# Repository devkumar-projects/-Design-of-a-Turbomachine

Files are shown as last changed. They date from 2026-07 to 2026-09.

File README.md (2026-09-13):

# Compact Axial Hydraulic Turbine — Integrated Turbomachinery Design

<p align="center">
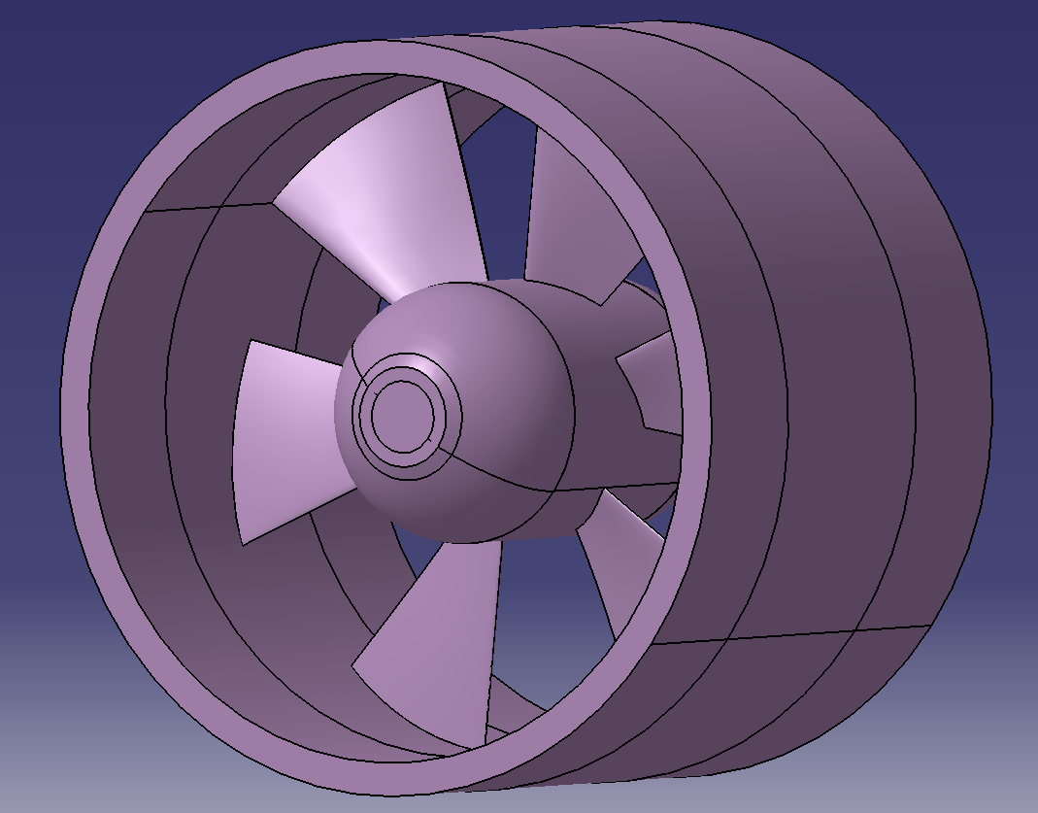
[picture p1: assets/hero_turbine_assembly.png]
Complete ducted axial-turbine CAD assembly
  
</p>

<p align="center">
  <em>Hydraulic sizing &middot; CAD &amp; structural verification &middot; CFD &middot; electromechanical conversion &middot; additive-manufacturing prototyping &middot; industrialisation</em>
</p>

<p align="center">
  
  
  
  
  
  
  
  
</p>

<p align="center">
  
</p>

## Overview

This repository documents the end-to-end engineering design of a **compact axial (Kaplan-type) hydraulic turbine**, carried out as a multidisciplinary study (*Bureau d'Etudes*) at **Arts et Metiers ParisTech (ENSAM)**. The project follows a single design thread from first principles to an industrial deployment scenario:

1. **Hydraulic preliminary sizing** in MATLAB, using similarity parameters and a digitised Cordier diagram.
2. **Blade-row and CAD modelling** in CATIA V5, with a preliminary finite-element check of the blade root.
3. **CFD analysis** in STAR-CCM+ (moving-reference-frame, steady segregated flow) to extract power, efficiency, and cavitation-risk trends.
4. **Electromechanical conversion**: a surface-mounted permanent-magnet synchronous generator pre-sized analytically and cross-checked with **FEMM/OctaveFEMM**, driving a PWM voltage-source converter modelled in **SIMBA**.
5. **Additive-manufacturing prototyping** (FFF, PLA) and **wind-tunnel testing** as a reduced-scale aerodynamic analogue of the hydraulic runner.
6. **Industrialisation study**: production planning, make-or-buy, location strategy, and a discounted business case for a 167-unit modular fleet.

The full write-up is included in [`docs/Compact_Axial_Hydraulic_Turbine_Report.pdf`](docs/Compact_Axial_Hydraulic_Turbine_Report.pdf).

> This was a **team project** (group GIE2-ED2, Semester 7): **Dev Kumar, Thien Ho, Seyf Daab, Wilhem Abboura**, supervised by **Christophe Sarraf, Florent Ravelet, Pascal Caestecker,** and **Jean-Frederic Charpentier**. This repository packages the MATLAB, FEMM, and SIMBA source files together with the consolidated report for portfolio purposes; the FEMM base template (`electromagnetic/femm`) was originally provided by J.-F. Charpentier and parameterised here for the project's operating point.

## Key results

| Stage | Metric | Value |
|---|---|---|
| Hydraulic design point | Speed / head / flow rate | 1500 rpm &middot; 3.8 m &middot; 0.132 m&sup3;/s |
| Runner envelope | Outer / hub radius | 103 mm / 39.1 mm |
| CFD baseline mesh | Cells / faces / vertices | 61,518 / 279,251 / 187,548 |
| CFD best operating point | Mechanical power @ flow rate | ≈ 1760 W @ 0.144 m&sup3;/s |
| Generator design torque | Electromagnetic torque | 152 N&middot;m |
| Prototype (wind-tunnel analogue) | Max. power coefficient / efficiency | C<sub>p</sub> ≈ 0.239 / η ≈ 0.56 |
| Industrial scenario | Fleet size / annual output | 167 units / ≈ 2 TWh/yr |
| Business case | ROI / payback | 21.5% / 2.4 years |

## Methodology

```mermaid
flowchart LR
    A[Cordier diagram\nsimilarity sizing] --> B[Velocity triangles\n+ blade mean line]
    B --> C[Modified NACA\nthickness law]
    C --> D[CATIA V5\nsurface + solid CAD]
    D --> E[Blade root FEA\nscreening]
    D --> F[STAR-CCM+ CFD\nmoving reference frame]
    F --> G[PMSM generator\nsizing + FEMM check]
    G --> H[PWM converter\n+ d-q current control\n SIMBA]
    D --> I[FFF prototype\n+ wind-tunnel test]
    F --> J[Industrialisation\n+ business case]
```

### Hydraulic sizing

The runner is sized from the engineering specific speed and the Cordier diagram:

```
Nsq = N * sqrt(qv) / H^0.75          (specific speed)
Omega = pi * Nsq / (30 * g^0.75)     (dimensionless specific angular velocity)
```

with the design point **N = 1500 rpm, N<sub>sq</sub> = 200, H = 3.8 m, q<sub>v</sub> = 0.132 m&sup3;/s**, giving an outer radius R<sub>e</sub> = 0.103 m and a hub radius R<sub>i</sub> = 0.039 m (hub-to-tip ratio 0.38).

Local velocity triangles then follow from the Euler turbine equation:

```
U(r)      = omega * r
Cu2_th(r) = -g*H / U(r)
beta_1(r) = atan( U(r) / Ca )
beta_2(r) = atan( (U(r) - Cu2(r)) / Ca )
```

### Electromechanical conversion

The generator's average electromagnetic torque follows from the fundamental air-gap flux density and the linear current loading:

```
<Cem> = sqrt(2) * B1 * A * V * cos(Psi)          (V = bore volume, A = linear current loading)
```

which is maximised for Ψ = 0 (current aligned with the EMF). The associated PWM converter is analysed for carrier-frequency sensitivity and closed-loop *d-q* current control.

## Repository structure

```
.
├── docs/
│   └── Compact_Axial_Hydraulic_Turbine_Report.pdf   # full write-up
├── matlab/
│   ├── hydraulic_sizing/     # Cordier sizing, velocity triangles, blade geometry, CATIA export
│   └── data_reduction/       # test-bench characteristic curves, affinity-law scaling
├── electromagnetic/
│   └── femm/                 # OctaveFEMM parametric PMSM field/flux/inductance script
├── simulink_simba/           # PWM converter + d-q current-control model (SIMBA)
├── cad/                      # STEP fluid-domain geometry used for the CFD study
├── data/                     # test-bench characteristic-curve dataset (multi-speed)
└── assets/                   # figures used in this README
```

## Tools and languages

| Domain | Tool |
|---|---|
| Hydraulic sizing, data reduction | MATLAB |
| Blade-section aerodynamics | XFoil |
| 3-D CAD, surfacing, structural screening | CATIA V5 (Generative Shape Design, Part Design, FEA) |
| CFD | Simcenter STAR-CCM+ |
| Electromagnetic field solving | FEMM / OctaveFEMM |
| Power electronics & control | SIMBA |
| Additive manufacturing | PrusaSlicer, FFF (PLA) |
| Experimental validation | Recirculating wind tunnel, 6-component balance |

## Selected figures

<table>
<tr>
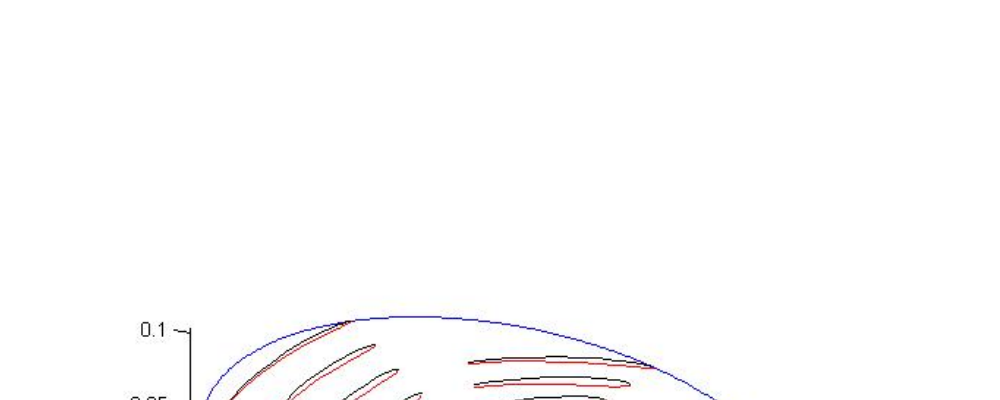
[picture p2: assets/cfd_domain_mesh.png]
<td><br><sub>Final blade-row geometry exported from the hydraulic sizing script</sub></td>
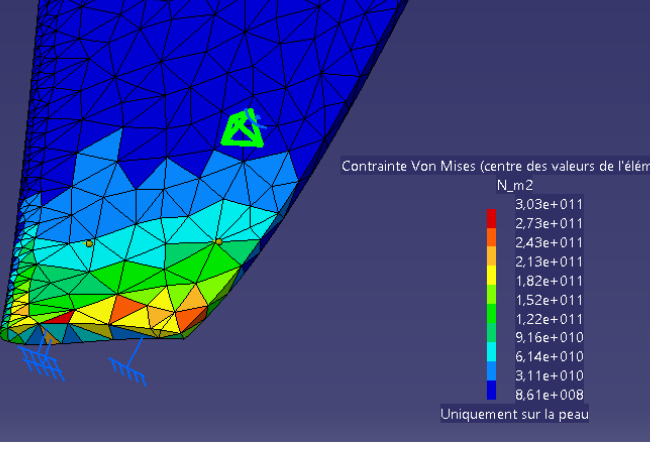
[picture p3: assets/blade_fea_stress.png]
<td><br><sub>Blade-root equivalent-stress distribution (finite-element screening)</sub></td>
</tr>
<tr>
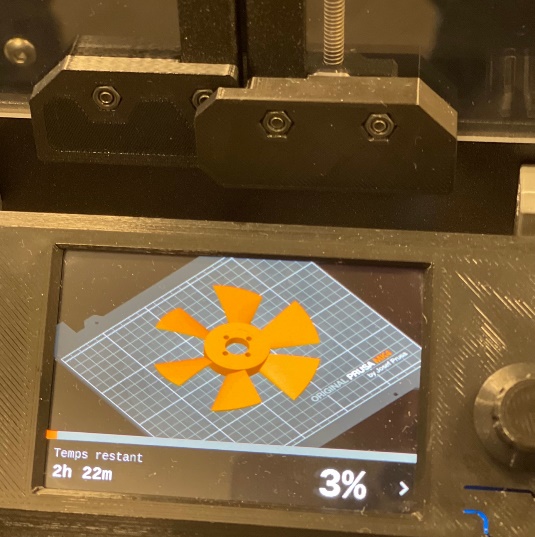
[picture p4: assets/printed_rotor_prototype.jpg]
<td><br><sub>FFF-printed PLA runner prototype</sub></td>
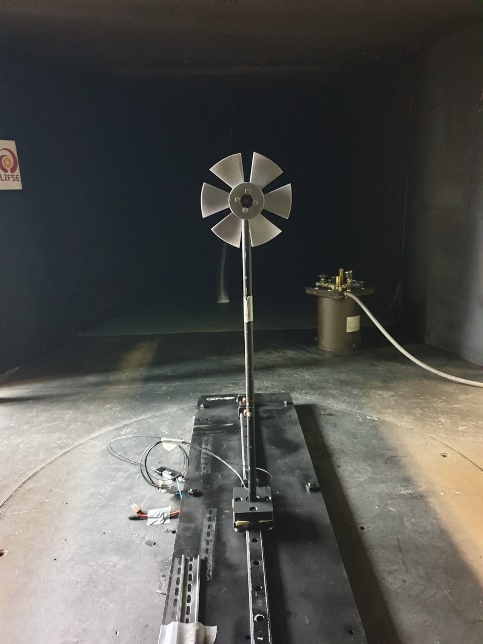
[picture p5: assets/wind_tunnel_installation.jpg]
<td><br><sub>Prototype installed in the recirculating wind-tunnel test section</sub></td>
</tr>
</table>

## Running the MATLAB scripts

```
matlab/hydraulic_sizing/main_turbine_sizing.m      % full sizing pipeline + CATIA point-cloud export
matlab/hydraulic_sizing/fit_naca_thickness.m       % modified NACA thickness-law identification (requires an XFoil point-save file)
matlab/hydraulic_sizing/cordier_digitisation.m     % Cordier-diagram specific-radius lookup
matlab/data_reduction/characteristic_curve_reduction.m   % reduces data/RIM_test_bench_data.xlsx into head/efficiency curves and BEPs
matlab/data_reduction/affinity_law_scaling.m       % turbine affinity-law speed scaling example
```

The FEMM script (`electromagnetic/femm/pmsm_femm_field_analysis.m`) requires a local [FEMM](http://www.femm.info/) installation and the OctaveFEMM/MATLAB toolbox. Set the `FEMM_MFILES` environment variable to FEMM's `mfiles` directory before running; the script no longer assumes a machine-specific Windows path or modifies MATLAB's global path.

The SIMBA model (`simulink_simba/pwm_converter_speed_control.jsimba`) can be opened directly in [SIMBA](https://simba.education/).

## License

This project is released under the [MIT License](LICENSE).

## Contact

Dev Kumar &middot; [dev-kumar.com](https://dev-kumar.com) &middot; contact@dev-kumar.com

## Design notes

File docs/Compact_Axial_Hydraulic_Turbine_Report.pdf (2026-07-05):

MULTIDISCIPLINARY ENGINEERING REPORT TURBOMACHINERY / ENERGY SYSTEMS

TURBOMACHINERY AND ENERGY CONVERSION

# Integrated Design of a Compact Axial Hydraulic Turbine

Hydraulic sizing, CAD and structural verification, CFD,
electromechanical conversion, prototyping, and industrialisation

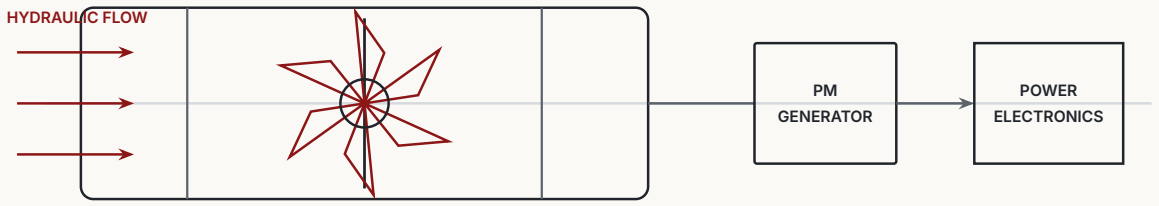
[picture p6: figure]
HYDRAULIC FLOW; PM GENERATOR; POWER ELECTRONICS

AUTHORS | Dev KUMAR · Thien HO · Seyf DAAB · Wilhem ABBOURA
SUPERVISORS | Christophe SARRAF · Florent RAVELET · Pascal CAESTECKER · Jean-Frédéric CHARPENTIER
INSTITUTION | École Nationale Supérieure d’Arts et Métiers
ACADEMIC TERM | Semester 7 — 2024 · Group GIE2–ED2
151 Boulevard de l’Hôpital, 75013 Paris, France

# Abstract

This report presents an integrated engineering study of a compact axial hydraulic turbine, from similarity-based hydraulic sizing to prototype testing and industrial deployment. The runner is pre-sized in MATLAB from a target speed of 1500 rpm, a specific-speed class Nsq = 200, a design head of 3.8 m, and an outer radius of 0.103 m. Velocity triangles and a modified NACA thickness law define the blade sections, which are exported to CATIA V5 for surface reconstruction, full rotor assembly, and preliminary finite-element verification. The resulting fluid domain is analysed in STAR-CCM+ using a moving reference frame and a baseline mesh of 61,518 cells. The reported optimum produces approximately 1760 W at 0.144 m³
s

−1
, below the initial 5 kW target and therefore motivating geometry refinement or a multi-unit architecture.
A surface-mounted permanent-magnet synchronous generator is then pre-sized from magnetic-circuit, induced-voltage, torque, and thermal relations. The associated voltage-source converter is examined through intersective PWM, carrier-frequency sensitivity, and closed-loop d–q current control. A PLA runner is manufactured by fused-filament fabrication and evaluated in a wind tunnel as a reduced-scale analogue. The experiment identifies a maximum power coefficient of approximately 0.239 and a peak efficiency of approximately 0.56. Finally, a modular industrial scenario based on 167 units is developed, including production planning, make-or-buy decisions, location strategy, and profitability. Under the source assumptions, the stated business case yields a 21.5% return on investment and a 2.4-year payback period. The study demonstrates the value of maintaining continuity between fluid mechanics, mechanical design, electrical conversion, experimental validation, and industrial decision-making.

KEYWORDS axial hydraulic turbine; Kaplan runner; Cordier diagram; STAR-CCM+; permanent-magnet synchronous generator; PWM converter; additive manufacturing; industrialisation.

i

# Project at a Glance

Ducted axial-turbine assembly developed in CATIA V5 and used to prepare the computational fluid domain.

HYDRAULIC DESIGN

N = 1500 rpm, H = 3.8 m, qv = 0.132 m³ s

−1
, Re = 0.103 m, and Ri =
0.03914 m.

DIGITAL ENGINEERING

MATLAB/XFoil blade synthesis, CATIA V5 surface and solid modelling, structural screening, and STAR-CCM+ moving-reference-frame CFD.

CFD BASELINE

61,518 cells, 279,251 faces, and 187,548 vertices; reported optimum P ≈ 1760 W at qv ≈ 0.144 m³
s

−1

EXPERIMENTAL RESULT

Additively manufactured PLA prototype; maximum measured power coefficient Cp ≈ 0.239 and peak efficiency η ≈ 0.56.

INDUSTRIAL SCENARIO

167 modular units, approximately 2 TWh/year target output, stated ROI 21.5%, and stated payback 2.4 years.

The equations, figures, numerical outputs, and engineering assumptions are retained from the original project report. The English prose, hierarchy, captions, scientific discussion, and publication design have been comprehensively edited for clarity and professional presentation.

ii

# Nomenclature

N , ω | Rotational speed and angular velocity.
Nsq, Ω | Engineering specific speed and dimensionless specific angular velocity.
H , qv | Net head and volume flow rate.
Re

, Ri

, r | Runner outer radius, hub radius, and local radius.
Ca
, U , Cu | Axial velocity, blade peripheral speed, and whirl-velocity component.
β1

, β2

, α2 | Blade inlet angle, blade outlet angle, and absolute discharge angle.
η, Cp | Efficiency and power coefficient.
P, M, C | Power and mechanical/electromagnetic torque.
B, H , μ | Magnetic flux density, magnetic field strength, and permeability.
p | Number of pole pairs.
ea

, eb

, ec | Phase electromotive forces.
id
, iq | Direct- and quadrature-axis current components.
Vdc, fc | DC-link voltage and PWM carrier frequency.
L, R, τ | Electrical inductance, resistance, and current-loop time constant.
Cp = 2P/(ρSV ³
) Aerodynamic power coefficient used in the wind-tunnel analogy.

iii

# Contents

1 Introduction | 1
2 Hydraulic Preliminary Design | 2
3 CAD Modelling and Structural Verification | 8
4 Computational Fluid-Dynamics Analysis | 11
5 Electromechanical Conversion System | 14
6 Additive Manufacturing and Experimental Validation | 26
7 Industrialisation and Market Deployment | 30
8 Conclusion | 39
A MATLAB and XFoil Routines | 40

iv

# List of Figures

2.1 Digitised Kaplan-turbine region of the Cordier diagram | | 2
2.2 MATLAB interpolation of the Cordier data used to identify the specific radius | | 3
2.3 Graphical solution used to determine the design head | | 4
2.4 Radial distribution of blade speed and whirl-velocity components | | 4
2.5 MATLAB output for inlet, outlet, and discharge angles at selected radii | | 5
2.6 Construction of the blade-section mean line from the local inlet and outlet angles | | 5
2.7 Relative blade-thickness law from hub to tip | | 6
2.8 Comparison between the initial NACA profile and the modified, thicker section | | 6
2.9 MATLAB reconstruction of the blade section from raw points and the fitted thickness law. . . . | 6
2.10 Optimised polynomial coefficients returned by MATLAB | | 7
2.11 Final blade-row geometry obtained after scaling and circumferential replication | | 7
3.1 Transfer of the analytical blade definition into the CAD environment | | 8
3.2 Equivalent-stress distribution in the blade under the prescribed surface loading | | 9
3.3 Progressive construction of the complete runner | | 9
3.4 Complete ducted-turbine CAD assembly | | 9
3.5 Principal CAD dimensions of the ducted runner | 10
3.6 Fluid-domain volumes extracted from the complete CAD assembly | 10
4.1 Computational-domain definition and baseline discretisation | 11
4.2 Detail of the computational mesh in the runner region | 12
4.3 Convergence assessment of the baseline CFD computation | 12
4.4 Representative CFD field used for performance interpretation | 12
4.5 Performance curves extracted from the STAR-CCM+ operating-point sweep | 13

5.1 Cross-section of the permanent-magnet synchronous machine used for the preliminary model. . 14
5.2 Winding layout, showing the outgoing and return conductors for each phase | 14
5.3 Stator-fixed angular reference used for the harmonic field representation | 15
5.4 Flux-cutting principle for a conductor moving through a magnetic field | 15
5.5 Idealised radial air-gap flux-density waveform created by the surface magnets | 17
5.6 Sizing interface used to define the generator geometry and magnetic loading | 19
5.7 Numerical outputs of the preliminary generator-sizing model | 19
5.8 Global speed-control architecture implemented in the simulation environment | 20
5.9 Representative ideal-source and PWM voltage waveforms | 21
5.10 Time-domain and spectral comparison of the ideal and PWM voltages | 21
5.11 PWM phase voltage compared with the ideal sinusoidal phase voltage | 21
5.12 Discrete Fourier transform of the converter output | 22
5.13 Ideal and PWM-fed phase-current comparison | 22
5.14 Modified carrier-frequency and inductance configuration | 23
5.15 Comparison used to assess the influence of carrier frequency | 23
5.16 Voltage and current response after increasing the DC-link voltage limit to 350 V | 24
5.17 Torque-model implementation and sensitivity to the current-to-EMF angle | 24
5.18 Principal blocks of the closed-loop current-control model | 24
5.19 Rotational-speed reference, measured speed, and electromagnetic torque | 25
5.20 Current components and their references during the speed-control sequence | 25
6.1 Preparation and execution of the fused-filament fabrication process | 26
6.2 Sliced geometry and support strategy | 26
6.3 Post-processing stages of the additively manufactured turbine | 27

v

vi List of Figures

6.4 Installed turbine prototype in the wind-tunnel test section | 27
6.5 Schematic representation of the recirculating wind-tunnel facility | 29
6.6 Wind-tunnel installation of the turbine prototype | 29
7.1 Comparison of potential French regions for turbine industrialisation and deployment | 31
7.2 Comparison of turbine technologies for the selected regional conditions | 33
7.3 Large Kaplan units compared with smaller modular turbines | 33
7.4 Compact bulb-turbine concept adopted for the industrial scenario | 34
7.5 Sales and operations plan, including annual production and safety stock | 34

CHAPTER 1

# Introduction

Hydraulic turbines have converted the energy of flowing water into useful mechanical power for centuries. From early water wheels to modern axial-flow machines, their development has been driven by the same engineering objective: extracting energy efficiently while maintaining structural integrity and operational reliability. In the present context of decarbonisation, distributed generation, and grid resilience, small and medium hydroelectric systems remain particularly attractive because they combine a mature conversion principle with low operational emissions and long service life.
This project addresses the end-to-end design of a compact axial hydraulic turbine and its associated electromechanical conversion chain. The work deliberately spans several engineering disciplines. Hydraulic preliminary sizing is first performed in MATLAB using similarity parameters and the Cordier diagram. Blade sections are then generated with XFoil-derived profiles and transferred to CATIA V5 for three-dimensional modelling and structural verification. The complete flow domain is analysed in STAR-CCM+ to assess the velocity and pressure fields, mechanical power, efficiency, and cavitation risk. A permanent-magnet synchronous generator and its power-electronic conversion chain are subsequently pre-sized and studied. Finally, a polymer prototype is manufactured by fused-filament fabrication, tested in a wind tunnel as an aerodynamic analogue, and embedded in an industrial and commercial deployment study.
The study is therefore organised around six coupled work streams:
1. Hydraulic preliminary design - definition of the operating point, characteristic radii, velocity triangles, blade angles, and section thickness law.
2. Blade and turbine CAD - point-cloud export, surface generation, finite-element verification, and construction of the complete rotor and fluid domains.
3. Computational fluid dynamics - mesh generation, moving-reference-frame simulation, convergence assessment, performance extraction, and cavitation screening.
4. Electromechanical conversion - preliminary design of a surface-mounted permanent-magnet synchronous generator and analysis of the PWM-fed variable-speed drive.
5. Prototype manufacture and experimental validation - additive manufacture, wind-tunnel measurements, and identification of the power coefficient and efficiency.
6. Industrialisation - market positioning, production planning, resource requirements, make-or-buy decisions, location strategy, and financial viability.

The resulting document is intended as a coherent engineering publication rather than a sequence of isolated laboratory exercises. Assumptions are stated explicitly, equations are retained in their original mathematical form, and each numerical stage is connected to the physical design decisions that follow.

1

CHAPTER 2

# Hydraulic Preliminary Design

### 2.1 Design brief and operating point

The first stage establishes a hydraulic pre-design for an axial-flow turbine. The initial specification is:
- rotational speed: N = 1500 rpm;
- specific-speed class: Nsq = 200;
- maximum available net head: H = 4 m;
- penstock and runner outer radius: Re = 0.103 m.
The process comprises three linked tasks: MATLAB-based sizing of the runner, construction of the blade geometry, and subsequent preparation of the complete fluid domain for CFD analysis. The MATLAB implementation is reproduced in the appendices.

### 2.2 Similarity parameters and Cordier selection

The angular velocity is

ω =

2 × π × N
60

= 157.07 rad.s⁻¹

The dimensionless specific angular velocity is written as

Ω = ω√qv
(gH )

3
4

=

π.N
30

×√qv
(gH )

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
Nsq =

N√qv
H

3/4,
which gives

Ω=

π.Nsq
30.g

3
4

= 3.778.

The Kaplan region of the Cordier diagram was digitised with Engauge and imported into MATLAB. This provided a reproducible estimate of the specific radius rather than a purely graphical reading.

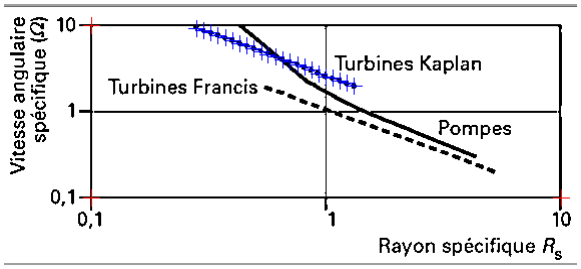
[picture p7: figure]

Figure 2.1: Digitised Kaplan-turbine region of the Cordier diagram.
The linear fit used in the selected interval is
Ω(Rs

) = 9.224−1.987
0.2804−1.31

Rs + 8.705 = −7.03Rs + 8.70. Solving Ω(Rs

) = 3.778 gives

2

Head, flow rate, and runner radii 3

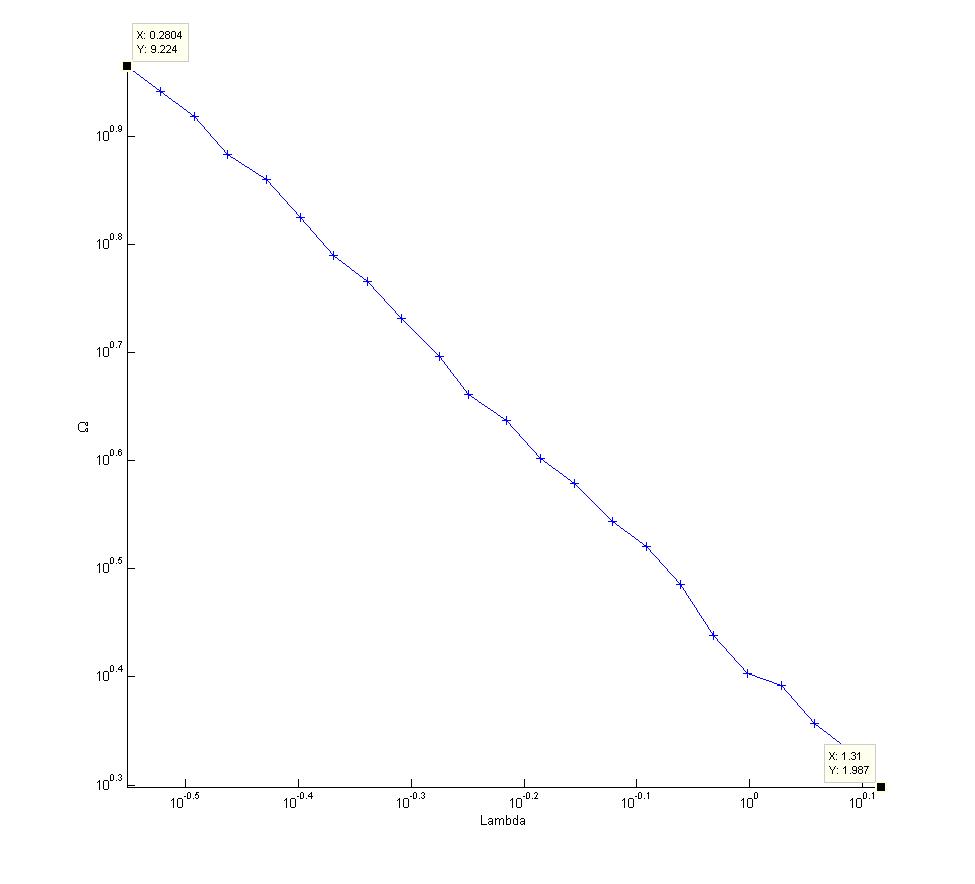
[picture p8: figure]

Figure 2.2: MATLAB interpolation of the Cordier data used to identify the specific radius.

Rs = 0.701.

### 2.3 Head, flow rate, and runner radii

The head and volume-flow relations are

Ω =

ω√qv
(gH )

3
4

, Λ =

R(gH )

1
4
√qv

The selected operating values are

H = 3.8 m
and
Nsq = | N√qv
| H
| 3
| 4

,

qv = 0.132 m³

| .s⁻¹
The hub radius is defined from the hub-to-tip ratio T = 0.38: Ri = ReT , with Re = 0.1030 m, hence

Ri = 0.03914 m.
The axial velocity component is

### 4 Hydraulic Preliminary Design

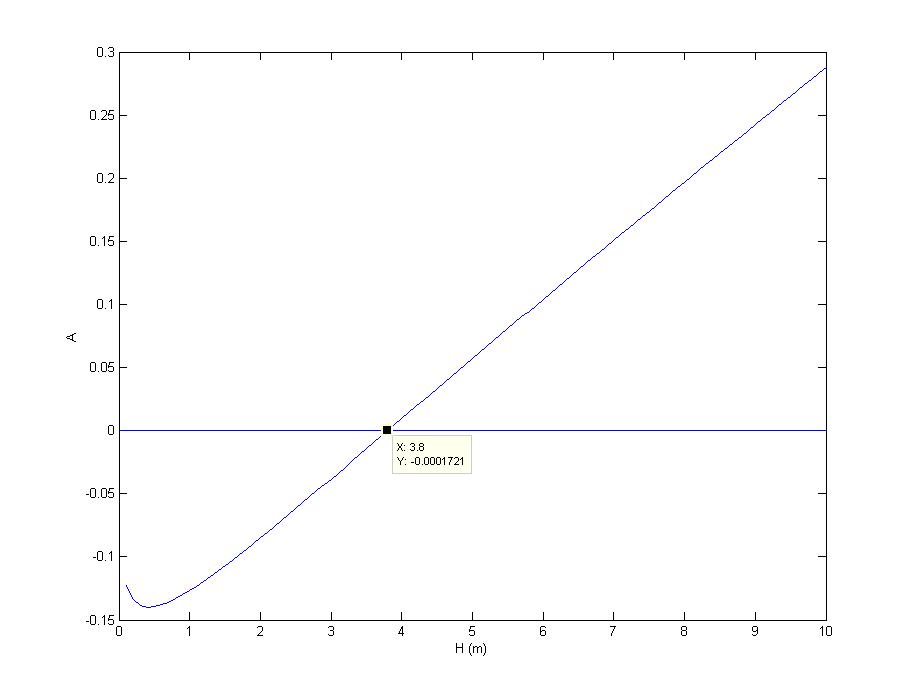
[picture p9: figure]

Figure 2.3: Graphical solution used to determine the design head.

Ca =

qv
S

=

qv
π (R²

e −R²
i

)

,

Ca = 4.629 m.s⁻¹
The circumferential speed and theoretical and corrected whirl components are evaluated over Ri < r < Re

Figure 2.4: Radial distribution of blade speed and whirl-velocity components.

### 2.4 Velocity triangles and blade mean line

The inlet, outlet, and discharge angles (β1

, β2

, α2

) are calculated directly in MATLAB from the local velocity triangles.
The calculated values of β1 and β2

remain between 30∘

and 80∘
, which is consistent with the adopted axialrunner design range. The blade-section mean line is generated by the function LigneK.m. Assuming a linear evolution of the local tangent between the inlet and outlet angles,

dyy = (tan β2 − tan β1

) xx2 + tan β1

Thickness law and modified NACA section 5

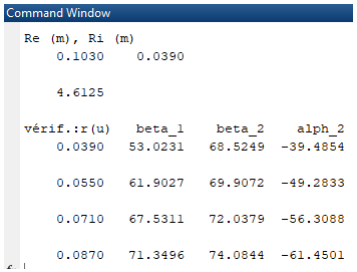
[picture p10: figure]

Figure 2.5: MATLAB output for inlet, outlet, and discharge angles at selected radii.

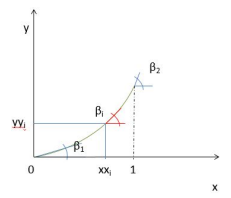
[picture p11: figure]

Figure 2.6: Construction of the blade-section mean line from the local inlet and outlet angles.

The full MATLAB routine is provided in Appendix A. It returns both the mean-line ordinate and the local blade angle required for the subsequent thickness distribution.

### 2.5 Thickness law and modified NACA section

Mechanical strength requires a blade that is thick near the hub and progressively thinner toward the tip. The adopted relative-thickness law is therefore defined as a function of radius.
Standard NACA profiles were found to be too thin for the intended prototype and structural constraints. A thicker profile was generated and fitted to a modified polynomial thickness law using XFoil data and MATLAB optimisation.
In the reconstruction, the red curve represents the upper surface, the green curve the normalised thickness law, and the blue curve the original point set. The function fminsearch(f,x0) is used to minimise the quadratic discrepancy between the measured and analytical profiles.
The resulting section is scaled according to the local solidity, defined here as the chordwise spacing relationship between adjacent blades. The final runner geometry is shown below.

### 6 Hydraulic Preliminary Design

Figure 2.7: Relative blade-thickness law from hub to tip.

Figure 2.8: Comparison between the initial NACA profile and the modified, thicker section.

Figure 2.9: MATLAB reconstruction of the blade section from raw points and the fitted thickness law.

Thickness law and modified NACA section 7

Figure 2.10: Optimised polynomial coefficients returned by MATLAB.

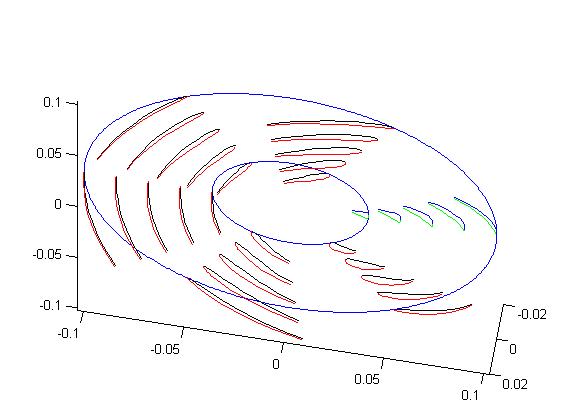
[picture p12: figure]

Figure 2.11: Final blade-row geometry obtained after scaling and circumferential replication.

CHAPTER 3

# CAD Modelling and Structural Verification

### 3.1 Point export and surface generation

Once the analytical blade geometry had been defined, MATLAB was used to decompose each section into a set of three-dimensional points. These point clouds were exported to CATIA V5, where the blade surfaces were reconstructed with the Generative Shape Design workbench. This workflow preserves the radial evolution of chord, thickness, and stagger angle while providing a CAD model suitable for both structural analysis and additive manufacture.

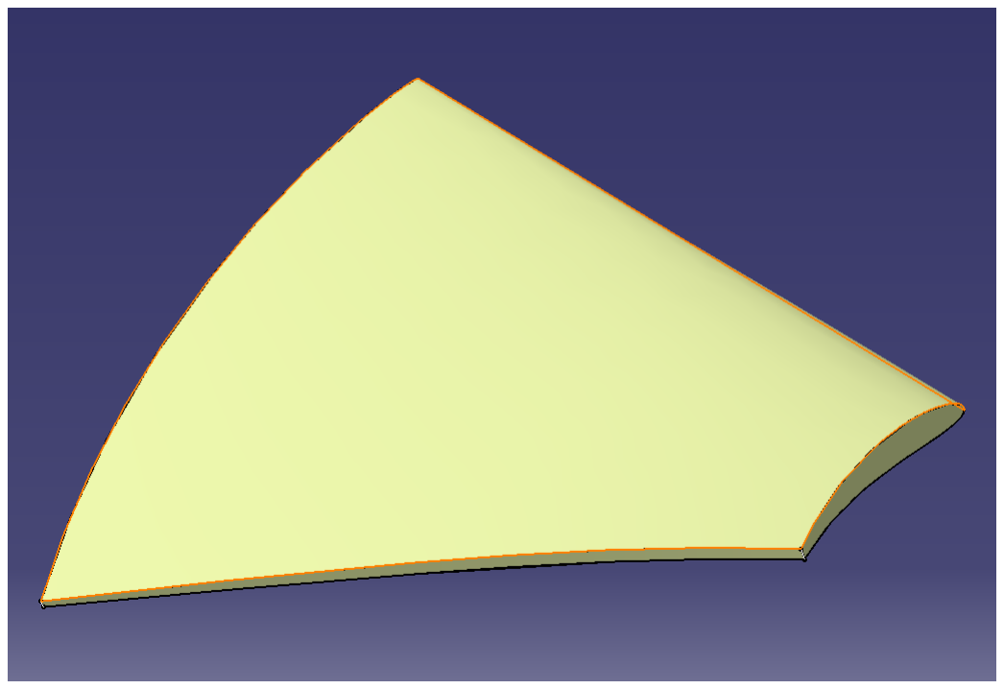
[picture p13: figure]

(a) MATLAB blade-section curves before CAD export. | (b) CATIA V5 surface reconstructed from the imported sections.

Figure 3.1: Transfer of the analytical blade definition into the CAD environment.

### 3.2 Finite-element verification of the blade

A preliminary finite-element analysis was performed to verify that the modelled blade could withstand the distributed fluid loading. Surface tractions were applied to the pressure and suction sides, while the blade root was fixed. The highest equivalent stresses occur, as expected, near the root constraint.
The maximum calculated stress remains below the elastic limit of the selected material within the assumptions of the model. The analysis therefore supports continuation to the full rotor assembly, while also identifying the root transition as the principal area for future mesh and geometry refinement.

### 3.3 Rotor, hub, and duct assembly

The individual blade was replicated circumferentially using the CATIA Part Design circular-pattern tool.
The hub was then modelled so that its outer diameter remained compatible with the blade-root envelope. A surrounding duct was divided into three axial regions. This partitioning was introduced specifically to define the inlet, rotating, and outlet fluid-domain interfaces required by STAR-CCM+.
A two-dimensional drawing was generated to retain the principal dimensions and assembly envelope. Finally, the solid geometry was used to construct the fluid volumes for CFD.

8

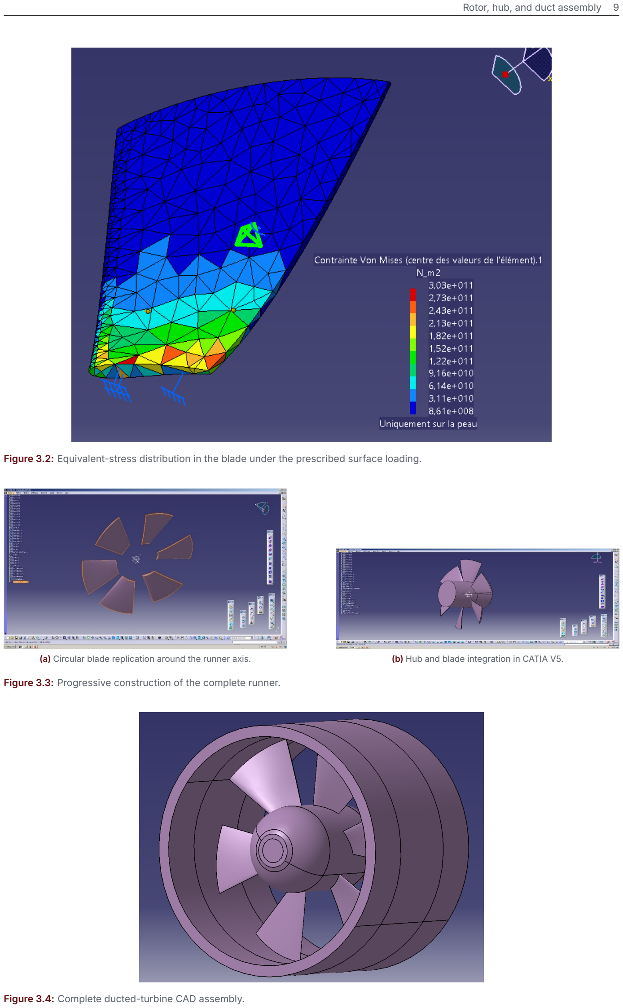
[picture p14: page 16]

Rotor, hub, and duct assembly 9

Figure 3.2: Equivalent-stress distribution in the blade under the prescribed surface loading.

(a) Circular blade replication around the runner axis. | (b) Hub and blade integration in CATIA V5.

Figure 3.3: Progressive construction of the complete runner.

Figure 3.4: Complete ducted-turbine CAD assembly.

### 10 CAD Modelling and Structural Verification

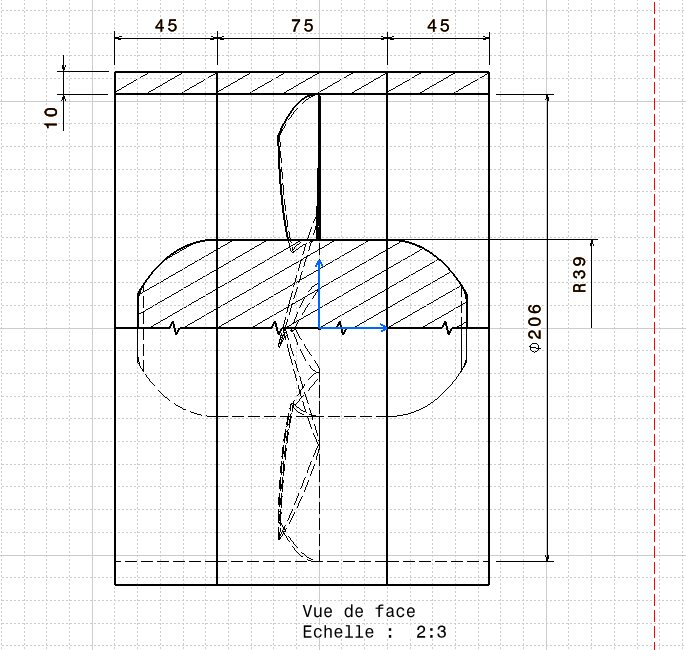
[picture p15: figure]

Figure 3.5: Principal CAD dimensions of the ducted runner.

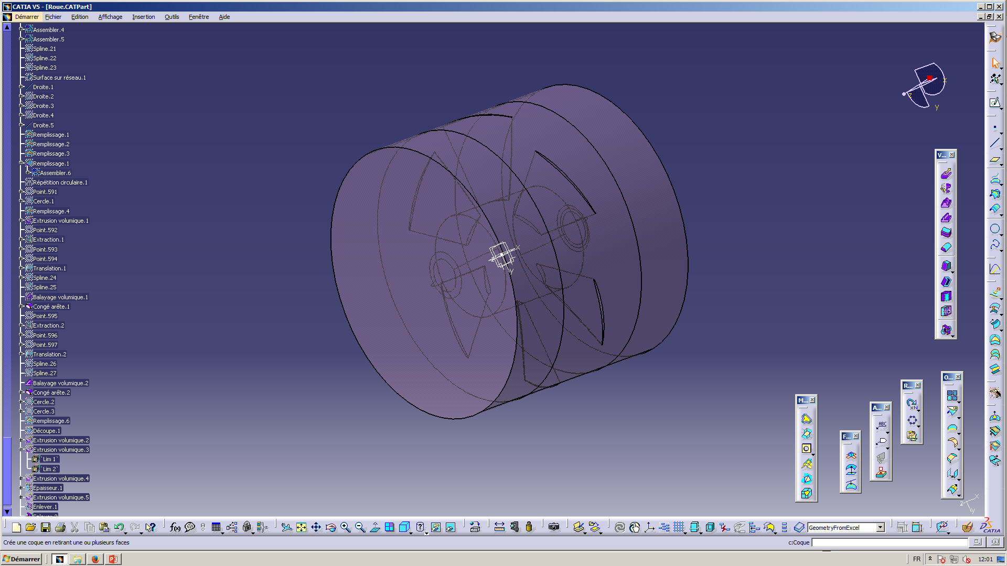
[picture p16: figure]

Figure 3.6: Fluid-domain volumes extracted from the complete CAD assembly.

CHAPTER 4

# Computational Fluid-Dynamics Analysis

### 4.1 Numerical model and mesh

The STAR-CCM+ study was configured to verify the following design targets:

- N = 1500 rpm;
- Nsq = 200;
- H = 4 m;
- R = 0.103 m;
- target hydraulic efficiency η = 0.92;
- target power P = 5 kW.

The inlet and outlet surfaces were defined at the ends of the extended flow domain. Additional upstream and downstream lengths were retained to prevent the solution from being dominated by the immediate blade-wake structures.
A combined surface and volume mesh was generated.
(a) Inlet, rotating-domain interfaces, and outlet. | (b) Surface and volume mesh of the fluid domain.

Figure 4.1: Computational-domain definition and baseline discretisation.

The baseline mesh contains 61,518 cells, 279,251 faces, and 187,548 vertices.

### 4.2 Physical models and reference frame

A segregated-flow formulation was selected to reduce computational cost and memory demand while maintaining acceptable convergence for the available computing resources. Rotor motion was represented with a moving reference frame. This formulation permits the rotating region to be treated in a steady framework while preserving the apparent inertial effects associated with rotation. The reference pressure was set to 101,300 Pa.

11

### 12 Computational Fluid-Dynamics Analysis

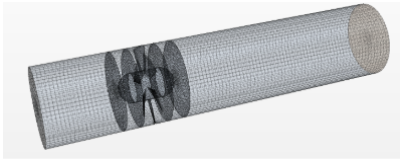
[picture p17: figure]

Figure 4.2: Detail of the computational mesh in the runner region.

### 4.3 Convergence assessment

The stopping criterion was set to 1000 iterations, with the residual level expected to fall below 10⁻³. The residual history confirms that this iteration count provides a sufficiently settled baseline solution for the present comparative design study.

(a) Residual convergence history. | (b) Independent monitor confirming solution stabilisation.

Figure 4.3: Convergence assessment of the baseline CFD computation.

If convergence were not achieved, the appropriate response would be to revisit the boundary conditions, pressure level, mesh quality, turbulence treatment, or iteration budget rather than interpreting an unconverged field.

### 4.4 Performance extraction and interpretation

The flow-field results were post-processed to obtain the hydraulic torque, mechanical power, and efficiency trends.

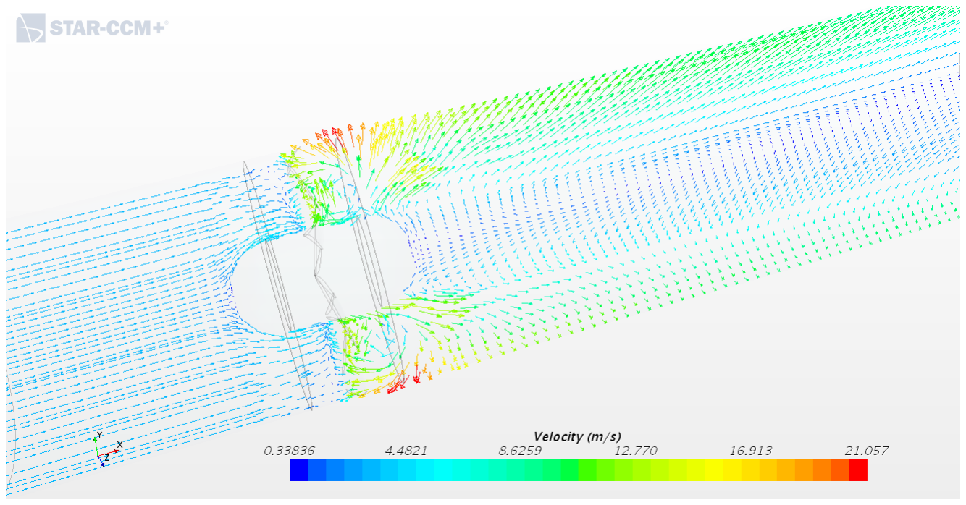
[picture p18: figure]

Figure 4.4: Representative CFD field used for performance interpretation.

The available mechanical power is calculated from

Pm = CΩ = MΩ.

Performance extraction and interpretation 13

Figure 4.5: Performance curves extracted from the STARCCM operating-point sweep.
The best simulated operating point occurs at approximately qv = 0.144 m³ .s

−1
, with a mechanical power of about 1760 W and a corresponding head of H = 3.60 m. This result does not reach the initial 5 kW target for a single unit, but it indicates that prioritising efficiency and using two units may be preferable to forcing one runner toward a less favourable operating point.
Cavitation becomes possible when the local static pressure falls below the saturation pressure. The highestrisk regions are therefore expected near leakage paths and blade edges, where local velocity peaks produce the strongest pressure depression.
The numerical study identifies four principal improvement directions:
- refine the blade-row geometry to optimise the balance between solidity, loading, and friction;
- increase mesh resolution in the blade boundary layers, tip region, and wake;
- revisit the single-unit 5 kW objective and evaluate a multi-unit architecture;
- adopt a less optimistic efficiency assumption during early-stage sizing.

Within the limits of the mesh and steady moving-reference-frame model, the CFD study completes the hydraulic pre-design and provides the loading and operating-point information required for the electrical and prototype stages.

CHAPTER 5

# Electromechanical Conversion System

### 5.1 Preliminary design of a permanent-magnet synchronous generator

The hydraulic runner is coupled to a surface-mounted permanent-magnet synchronous machine operated as a generator. The purpose of this section is to establish a first set of electromagnetic dimensions at the selected operating point and to derive the relationships governing induced voltage, electromagnetic torque, magnet loading, and active length.

Figure 5.1: Cross-section of the permanent-magnet synchronous machine used for the preliminary model.
The magnets are mounted on the rotor surface, surrounding the previously designed turbine. The ferromagnetic laminations form high-permeability magnetic circuits, while the phase windings are placed in stator slots.

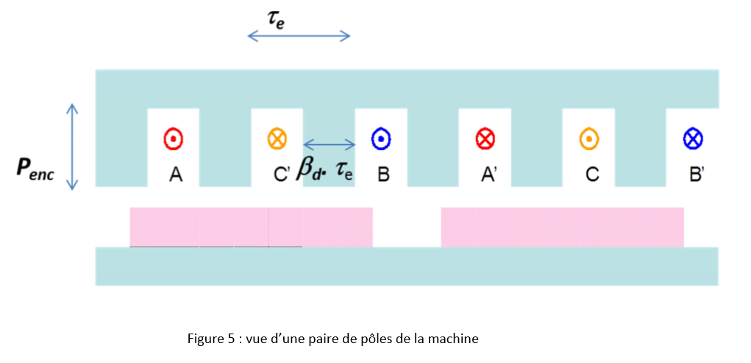
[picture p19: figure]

Figure 5.2: Winding layout, showing the outgoing and return conductors for each phase.

The end effects are neglected, allowing the machine to be analysed in two dimensions. The model therefore assumes an axially uniform machine in which the displayed section is representative of any section along the

14

Preliminary design of a permanent-magnet synchronous generator 15

active length. The permeability of the ferromagnetic yokes is treated as very high relative to the air gap and magnet regions.

### 5.1.1 Preliminary magnetic relations

For a linear medium,
B = μ ⃖⃗ H⃖⃖⃗.
For air,
⃖⃖⃖⃗ B0 = μ0
| ⃖⃖⃖⃗ H0 ,
and for the iron,
B = μ ⃖⃗ 0μrH⃖⃖⃗, with μr > 1000. For the permanent magnet,

⃖⃗B=μ0

⃖⃖⃗H+⃖⃖⃖⃗ Br

### 5.1.2 Electromotive forces and average torque

When the rotor turns relative to the stator, the magnet field induces phase electromotive forces. In a stator-fixed reference frame,

Figure 5.3: Stator-fixed angular reference used for the harmonic field representation.

B (θ, t) =

∞
∑
k=0

B2k+1cos[p (2k + 1) (θ − Ωt)],

where p is the number of rotor pole pairs and Ω is the mechanical angular velocity in radians per second. The flux-cutting relation is illustrated below.

Figure 5.4: Flux-cutting principle for a conductor moving through a magnetic field.

For a conductor moving at velocity ⃖⃗v,

e = l |

⃖⃗BΛ⃖⃗v| = lBv if ⃖⃗B⟂⃖⃗v.

With LxB = φ,
dφ
dt =

dx
dt LB = vLB.

### 16 Electromechanical Conversion System

For phase A, with D denoting the air-gap diameter,

econdA= B (0, t) ∗

ΩD
2

L,

econdA′ = B (

π
2

, t)

ΩD
2

L = −econdA.

Because one turn contains two active conductors, N conductors correspond to N /2 turns. Accounting for the pole count, the phase-A electromotive force becomes

ephaseA=ΣecondA−ΣecondA′= nB (0, t)

ΩD
2

L.

The two other phase voltages are shifted by 2π/3 and 4π/3:

ephaseB= nB (

2π
3p

, t)

ΩD
2

L,

ephaseC= nB (

4π
3p

, t)

ΩD
2

L.

Assuming balanced sinusoidal currents,

i
i

(t) = I√2 cos (ωt − Ψ − (i − 1) 2π 3

) , ω = pΩ.

The instantaneous electromagnetic power is

Pem(t) =

3
∑
i=1

ei

i

i = n

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
Bk+1 cos [(2k + 1) ((i − 1) 2π 3

− ωt)] cos (ωt − Ψ − (i − 1) 2π 3

) .

All higher-order terms have zero mean over an electrical period; only the fundamental contributes to the average power:

⟨pem⟩ = I√2nΩD
2

L

3
∑
i=1

B1 cos ((i − 1) 2π
3

− ωt) cos (ωt − Ψ − (i − 1) 2π 3

) ,

⟨pem⟩ =

3
2

I√2nΩD
2

Lcos(Ψ).

Using the linear current loading A = 3nI
πD

and bore volume V = πD²L
4

= πR²L,

⟨Cem⟩ =

⟨pem⟩
Ω

=

3
2√2

nB1

IDL cosΨ = 3
2√2

AπD
3

DB1L cosΨ,

⟨Cem⟩ =√2B1AV cos(Ψ).
The maximum torque is obtained for Ψ = 0:

⟨Cem⟩max =√2B1AV.

### 5.2 Magnet thickness and fundamental air-gap flux density

The air gap is assumed sufficiently small for the induction in the gap and the magnet to be predominantly radial. Curvature and load-current effects are neglected, and the ferromagnetic yokes are assumed to have infinite permeability. The magnet characteristic is
B = μ0H + Br
Ampere’s law is applied to a contour crossing the two magnets and the two air gaps:

Magnet thickness and fundamental air-gap flux density 17

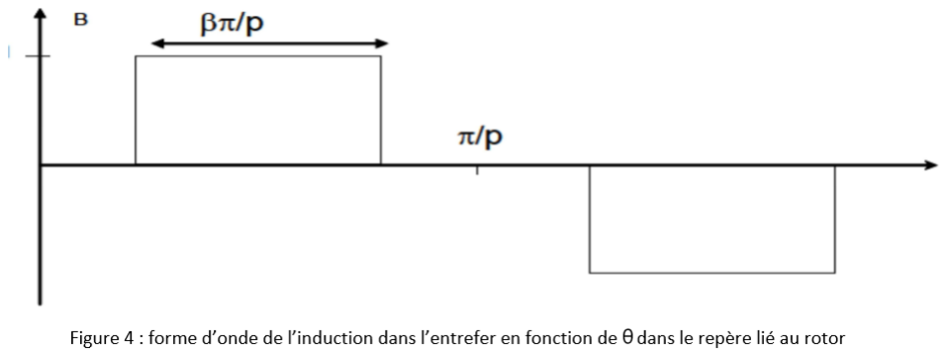
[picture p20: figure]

Figure 5.5: Idealised radial air-gap flux-density waveform created by the surface magnets.

⃖⃖⃖⃗ rot (H⃖⃖⃗) = J →⃖⃗

⎧
⎨
⎩
B = μ ⃖⃗ | 0H⃖⃖⃗ in air
B = μ ⃖⃗ | 0μrH⃖⃖⃗ in iron, μr > 1000
B = μ ⃖⃗ | 0H + ⃖⃖⃗ ⃖⃖⃗Br
in the magnet
Because no current is enclosed,

∮ H ⋅ ⃖⃖⃗ ⃖⃖⃗dl = 0.

The field intensity in the iron is negligible compared with that in the air gap:
Hf er =

Bf er
μ0μr

≪ Hair .
The magnetic-circuit equation therefore reduces to

2Haea + 2Hgg = 0, Ba = Bg = ̂B.

With
⎧
⎪
⎨
⎪
⎩

Bg = μ0Hg → Hg =

B̂
μ0
Ba = μ0Ha + Br
Ha =

B−B ̂ r
μ0

,

one obtains

̂B=

eaBr
g + ea

For g = 1 mm and ea varied from 0.1 to 10 mm, the relationship is initially nearly linear and asymptotically approaches Br

. Excessive magnet thickness therefore adds material with progressively smaller electromagnetic benefit.
The first harmonic of the rectangular air-gap field is

a1 =

2
T

∫

T /2

−T /2

f (T ) cos(ωt)dt,

which gives

B1 = a1 =

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
B(θ) cos(pθ)dθ = 4
π

B̂sin (

βπ
2

) ,

B1=

4
π

̂Bsin (

βπ
2

) .

### 18 Electromechanical Conversion System

### 5.3 Dimensional model at the nominal operating point

The machine is sized for a nominal power and speed (Pn

, Ωn

). The principal prescribed quantities are summarised below.

Symbol Definition
J | RMS current density in the conductors (A/mm²
)
AL

linear current loading
kr

slot fill factor
D | air-gap diameter
Be,max | maximum air-gap induction
Br | magnet remanent flux density
g | air-gap length
Bsat | saturation flux density
fmax | maximum electrical frequency

The slot fill factor is

kr =

∑ Scond

Sslots

,

where Scond is the conductor cross-sectional area.

### 5.3.1 Thermal and electromagnetic constraints

Copper losses and convection establish the principal thermal constraint:

PJ = 3nRcond I

2 = 3nρ L
Scond

I

2 = ρ3nI LJ = ρπDL AJ ,

ΔT ∼

PJ

ℎSext

, Sext ∼ πDL,

ΔT ∼

ρAJ
h

Representative design ranges are

J ∈ [3 × 10⁶

, 7 × 10⁶

] A/m²
,

A ∈ [12,000, 60,000] A/m.
At the nominal point,

PN = CemΩN , Cem =

PN

ΩN

=

PN
πN
30p

,

which gives

Cem = 152 Nm.
The active length is selected while respecting magnetic saturation. With

X = B̂
Br

,

Variable-speed drive and PWM converter 19

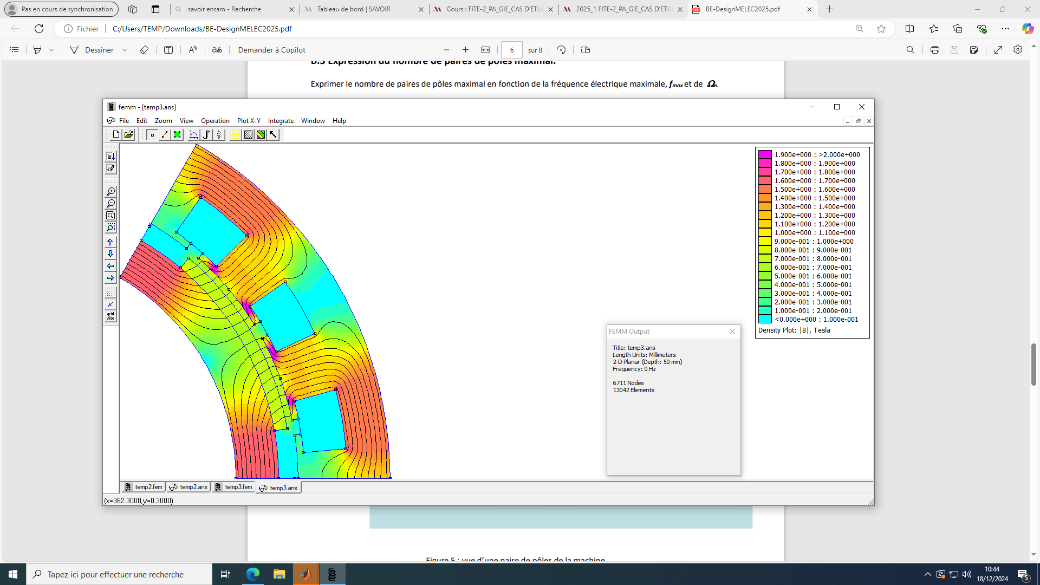
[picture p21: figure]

Figure 5.6: Sizing interface used to define the generator geometry and magnetic loading.

B = X B ̂ | r
, | B1 =

4
π

B̂sin (

βπ
2

) ,

Cem = √2AD²LBr

sin (

βπ
2

) ,

one obtains

L = | C
√2AXBrD²

sin (

βπ
2

)

The resulting parameter set is then introduced into the numerical model to calculate flux linkage as a function of rotor position and phase and to verify the electromagnetic design.

(a) Generator pre-sizing parameters and principal numerical results. | (b) Complementary machine-design output used for finite-element validation.

Figure 5.7: Numerical outputs of the preliminary generator-sizing model.

This stage provides a consistent first-order geometry for the permanent-magnet synchronous generator at the selected torque-speed point.

### 5.4 Variable-speed drive and PWM converter

The second electrical study concerns the conversion chain formed by the permanent-magnet synchronous machine and a voltage-source inverter controlled by pulse-width modulation (PWM). The objective is to understand the variable-speed control principle and evaluate the influence of switching and filtering parameters on the phase currents.

### 5.4.1 Global speed-control architecture

The rotating-system dynamics may be expressed in the generic form J

dΩ
dt = Cem − Cload ,
where J is the total rotating inertia, Ω the rotational speed, Cem the electromagnetic torque, and Cload the

### 20 Electromechanical Conversion System

torque imposed by the turbomachine.
The control structure compares the speed reference with the measured speed, uses a PI/PID controller to produce a torque reference, and applies vector control so that the phase currents remain synchronised with the machine electromotive forces.

Figure 5.8: Global speed-control architecture implemented in the simulation environment.

For phase i,

φi = φm√2 cos (θ − (i − 1) 2π 3

) ,

ei = −

dφi
dt =

dφi
dθ

dθ

dt = √2φmω sin (θ − (i − 1) 2π 3

) .

The electrical power relations are P = 3V I cos α,

Pe = 3EI cos ψ ,
and

Cem=

Pe
Ω

= 3 E
Ω

I cos ψ .

If the current-to-EMF angle is maintained constant, the torque is proportional to the sinusoidal current amplitude. Adjusting this amplitude therefore provides direct torque control while preserving synchronism with the machine EMFs.

### 5.4.2 Ideal source and intersective PWM comparison

The SIMBA model VSI-vs-Perfect-V compares two supply configurations:

1. an ideal three-phase sinusoidal voltage source;
2. a voltage-source inverter controlled by intersective PWM.

The PWM converter generates a pulse train whose duty ratio varies with the sinusoidal reference. The ideal source contains only the fundamental component, whereas the PWM voltage includes switching harmonics concentrated around the carrier frequency and its multiples.
A second converter analysis confirms the same behaviour.

Variable-speed drive and PWM converter 21

Figure 5.9: Representative ideal-source and PWM voltage waveforms.

Figure 5.10: Time-domain and spectral comparison of the ideal and PWM voltages.

Figure 5.11: PWM phase voltage compared with the ideal sinusoidal phase voltage.

### 22 Electromechanical Conversion System

The fundamental remains at 50 Hz, while additional components appear around 2 kHz and 4 kHz for the selected carrier frequency.

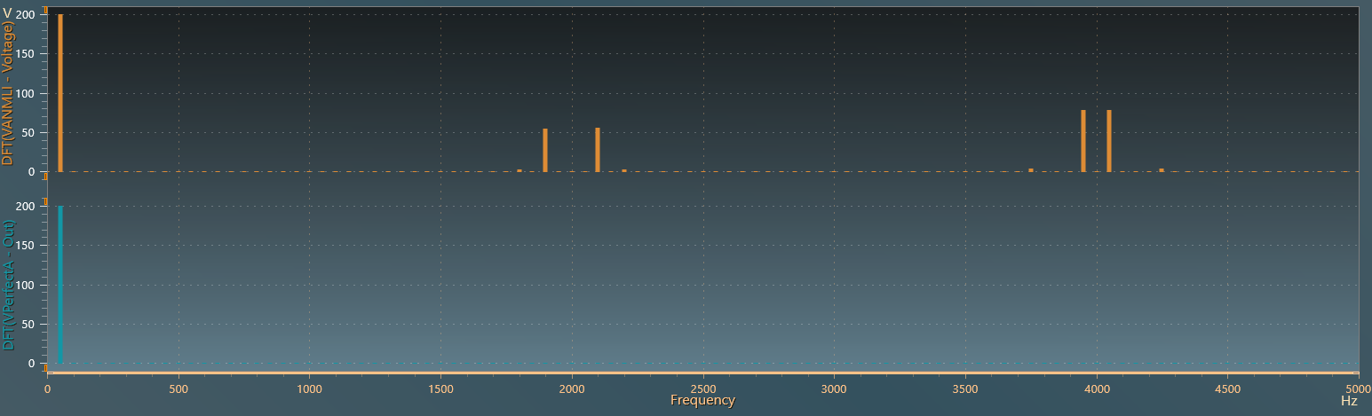
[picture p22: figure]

Figure 5.12: Discrete Fourier transform of the converter output.

The machine inductance attenuates the high-frequency voltage harmonics, but residual current ripple increases copper losses and can contribute to acoustic noise, torque ripple, and additional converter stress. Carrier frequency and filtering must therefore be selected jointly.
For the equivalent R-L phase circuit,

fc =

R
2πL

=

10
2π ⋅ 0.001

= 150 Hz,

τ =

L
R

=

0.001
10

= 1 ms.

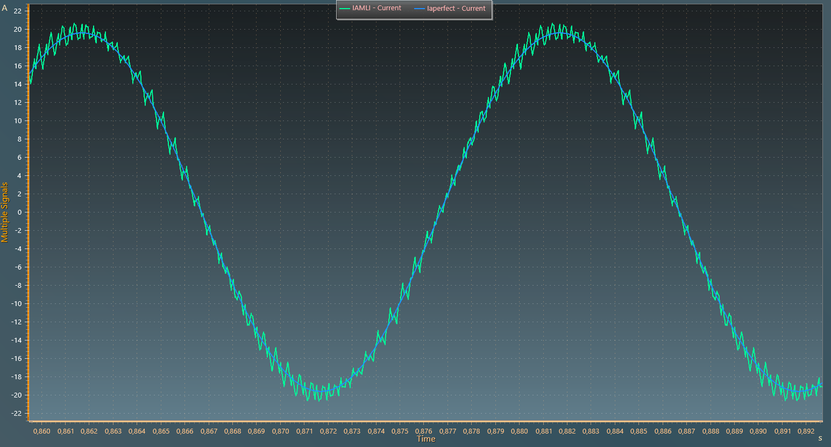
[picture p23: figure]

Figure 5.13: Ideal and PWM-fed phase-current comparison.
The ideal current is purely sinusoidal. The PWM-fed current contains ripple superimposed on the same fundamental. A DFT would therefore show an identical 50 Hz fundamental under correct scaling, with additional components clustered around multiples of the switching frequency.

### 5.4.3 Carrier-frequency and inductance study

The simulations were repeated with a carrier frequency of fPW M = 500 Hz and Ld = Lq = 0.01 H. The modified inductance reduces ripple, although a lower carrier frequency generally increases low-order current distortion and may reduce the accuracy of vector control.
The carrier-frequency trade-off is as follows:
- high carrier frequency (2000 Hz): lower current ripple and improved waveform fidelity, but higher semiconductor switching losses;

Variable-speed drive and PWM converter 23

(a) Current response. | (b) Associated voltage response.

Figure 5.14: Modified carrier-frequency and inductance configuration.

- low carrier frequency (500 Hz): lower switching losses, but greater current ripple and stronger reliance on inductive filtering.

Figure 5.15: Comparison used to assess the influence of carrier frequency.

Returning to the initial values improves current quality because of the higher modulation frequency, but increases switching losses and thermal loading. Increasing Vmax to 350 V expands the available voltage amplitude and converter dynamic range, while imposing higher electrical stress on the semiconductor devices and filters.

### 5.4.4 Closed-loop current control

Accurate phase-current control requires the applied voltage Vk

(t) to be adjusted in real time to compensate the resistive, inductive, and back-EMF terms while tracking Ik,r ef . In the vector-control architecture:

1. a Park transformation maps Ia

, Ib

, Ic

into the rotating d-q frame;
2. PI/PID loops regulate id and iq and generate Vd and Vq

;
3. PWM converts the voltage commands into switching signals for the inverter.

The d-q transformation decouples the flux-producing current from the torque-producing current. This is essential for achieving fast torque control with limited losses.
The large matrix block performs the reference-frame transformation and produces the modulated output signal supplied to the converter.
During each acceleration phase, the electromagnetic torque reaches its maximum before settling once speed regulation is established. During deceleration, the torque becomes negative to provide controlled braking. The complete chain therefore demonstrates the expected relationship between speed error, torque demand, and the regulated d-q currents.

### 24 Electromechanical Conversion System

Figure 5.16: Voltage and current response after increasing the DC-link voltage limit to 350 V.

(a) Electromagnetic-torque block. | (b) Torque response for Ψ = 0∘
. | (c) Responses for Ψ = 45∘

and 90∘

Figure 5.17: Torque-model implementation and sensitivity to the current-to-EMF angle.

(a) Matrix modulation and reference-frame transformations. | (b) Detailed current-control implementation.

Figure 5.18: Principal blocks of the closed-loop current-control model.

Variable-speed drive and PWM converter 25

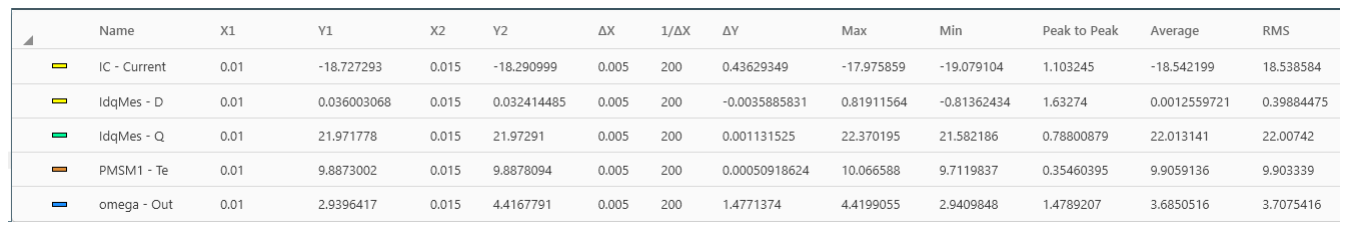
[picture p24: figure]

Figure 5.19: Rotational-speed reference, measured speed, and electromagnetic torque.

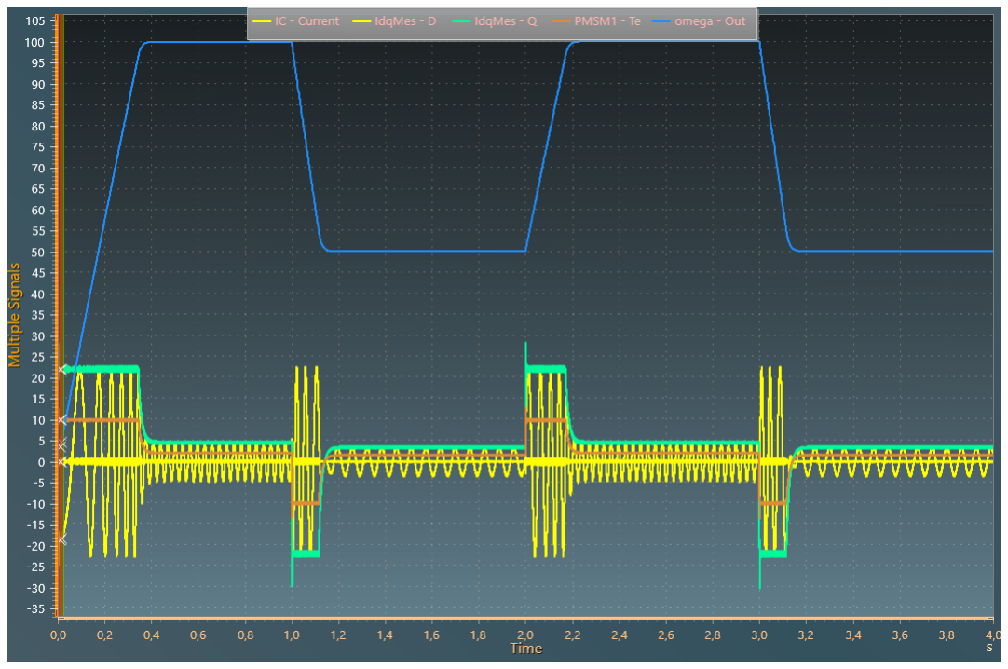
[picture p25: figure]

Figure 5.20: Current components and their references during the speed-control sequence.

CHAPTER 6

# Additive Manufacturing and Experimental Validation

### 6.1 Prototype preparation and manufacture

The final CAD model was imported into PrusaSlicer, oriented, supported, and divided into printable layers before manufacture by fused-filament fabrication.

(a) Geometry imported into PrusaSlicer. | (b) Prototype during the build. | (c) Printer settings and build monitoring.

Figure 6.1: Preparation and execution of the fused-filament fabrication process.

Figure 6.2: Sliced geometry and support strategy.

After the required supports had been removed, the complete prototype was obtained. The part was manufactured in polylactic acid (PLA), a widely used thermoplastic for rapid prototyping. The extrusion temperature was set to approximately 200∘C. The slicer defined the layer sequence, toolpaths, support geometry, and local build parameters required to reproduce the complex blade and hub geometry.
The original manufacturing note reports a filament diameter of 20 μm. In practice, this value is more representative of a layer-scale or positioning parameter than of commercial filament stock; the reported setting is nevertheless retained here as part of the experimental record.

26

Wind-tunnel test facility 27

(a) Turbine before complete support removal. | (b) Runner and support-structure detail. | (c) Final prototype after support removal.

Figure 6.3: Post-processing stages of the additively manufactured turbine.

### 6.2 Wind-tunnel test facility

The prototype was tested in a recirculating wind tunnel as an aerodynamic analogue of the hydraulic machine. The purpose was not to reproduce water-turbine Reynolds numbers exactly, but to identify the qualitative performance curve, optimal rotational speed, and mechanical power trend under controlled flow conditions.

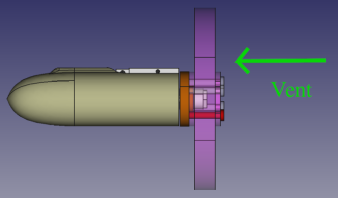
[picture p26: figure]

Figure 6.4: Installed turbine prototype in the wind-tunnel test section.

The facility is a return-circuit tunnel with a semi-guided test section and a maximum flow velocity of approximately 40 m/s. The contraction accelerates the flow by a factor of about 12.5, producing a relatively uniform low-turbulence stream in the measurement section. The return-valve region, by contrast, exhibits a turbulence level of approximately 10%.

### 6.3 Measured quantities and performance coefficients

The quantities used in the test analysis are summarised below.

Quantity Definition | Expression or source
Cp | power coefficient | P/(0.5ρSV ³
)
P | mechanical power recovered at the shaft Cω
C | rotor torque | experiment
ω | rotational speed | πN /30
V | upstream reference velocity | experiment

### 28 Additive Manufacturing and Experimental Validation

Quantity Definition | Expression or source
U | blade-tip circumferential speed | Rω
λ | tip-speed ratio | U /V
S | rotor-disc area | π (2R)²/4
R | blade-tip radius | 75 mm
ρ | air density | 1.2 kg/m³
Cc | torque coefficient | derived from Cp

A first measurement series was performed at a wind speed of 10 m/s to identify the rotational speed corresponding to the maximum power coefficient. The optimum was found near ω = 190.5 rad/s, with

| Cp,max = 0.239.
A second series varied the upstream velocity to determine mechanical power as a function of flow speed. The wind velocity was obtained from the measured pressure difference using

Vwind =

√
2ΔP
ρair

The available aerodynamic power is

Pavailable =

1
2

ρair SV ³
wind .

The experimental power trend increases approximately linearly over the measured range and remains consistent with the expected qualitative behaviour. The maximum experimental efficiency is approximately 0.56. This is below the 0.80-0.90 range typically associated with mature industrial hydraulic turbines, but the comparison must be interpreted cautiously because the prototype was tested in air, at reduced scale, with additive-manufacturing surface roughness and without complete hydraulic similitude.
The experiment nevertheless validates the mechanical integrity of the prototype and confirms that the designed rotor develops a measurable torque and power maximum. It also identifies clear routes for improvement: reduced surface roughness, a more precise hub and tip clearance, higher-fidelity instrumentation, Reynoldsnumber scaling, and ultimately testing in a water loop.

Measured quantities and performance coefficients 29

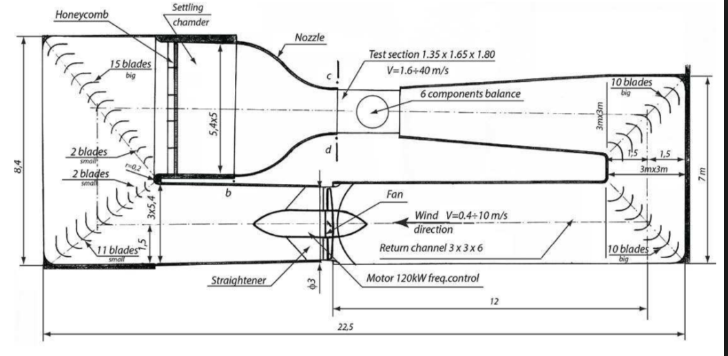
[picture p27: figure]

Figure 6.5: Schematic representation of the recirculating wind-tunnel facility.

(a) Prototype and instrumentation in the test section. | (b) Alternative view during the experiment.

Figure 6.6: Wind-tunnel installation of the turbine prototype.

CHAPTER 7

# Industrialisation and Market Deployment

### 7.1 Industrialisation framework

The industrial study translates the engineering concept into a production and deployment scenario. Hydroelectric power is treated as a mature renewable-energy option capable of supporting regional decarbonisation, reducing dependence on fossil generation, and providing long-lived infrastructure. The proposed industrialisation plan addresses not only technical performance, but also cost, capacity, logistics, sourcing, and market access.
The scope includes:
- market analysis and regional site selection;
- a sales and operations plan, referred to in the original study as the Plan Industriel et Commercial (PIC);
- a master production schedule (MPS/PDP);
- Manufacturing Resource Planning II (MRPII);
- a manufacturing bill of materials (MBOM);
- assembly, takt-time, lead-time, and plant-layout considerations;
- make-or-buy and country-location decisions;
- investment, profitability, and payback analysis.

### 7.2 Market analysis and regional selection

Several French regions were compared in terms of hydroelectric potential, energy demand, logistics, and infrastructure access.
The Provence-Alpes-Cote d’Azur (PACA) region was selected in the original business scenario for five reasons:
1. Seasonal energy demand. The regional population and electricity demand increase strongly during the summer period, making additional local generation strategically valuable.
2. Hydroelectric potential. Although lower than that of Auvergne-Rhone-Alpes, the available resource is considered sufficient for distributed projects while retaining logistical and operational advantages.
3. Existing modernisation programmes. Ongoing infrastructure renewal and renewable-energy initiatives create a favourable project environment.
4. Logistical accessibility. Ports, road networks, and industrial infrastructure reduce equipment-distribution and installation complexity.
5. Environmental and economic co-benefits. Local manufacture and deployment can support employment and contribute to carbon-reduction objectives.
The industrial objective is to become a supplier of modular hydroelectric equipment for institutional customers and infrastructure operators. The study assumes annual regional investment exceeding EUR 50 million and seeks to combine high product quality with controlled cost, seasonal flexibility, and scalable production.

### 7.3 Turbine selection and product positioning

A comparative assessment of turbine technologies was performed.

30

Sales and operations plan 31

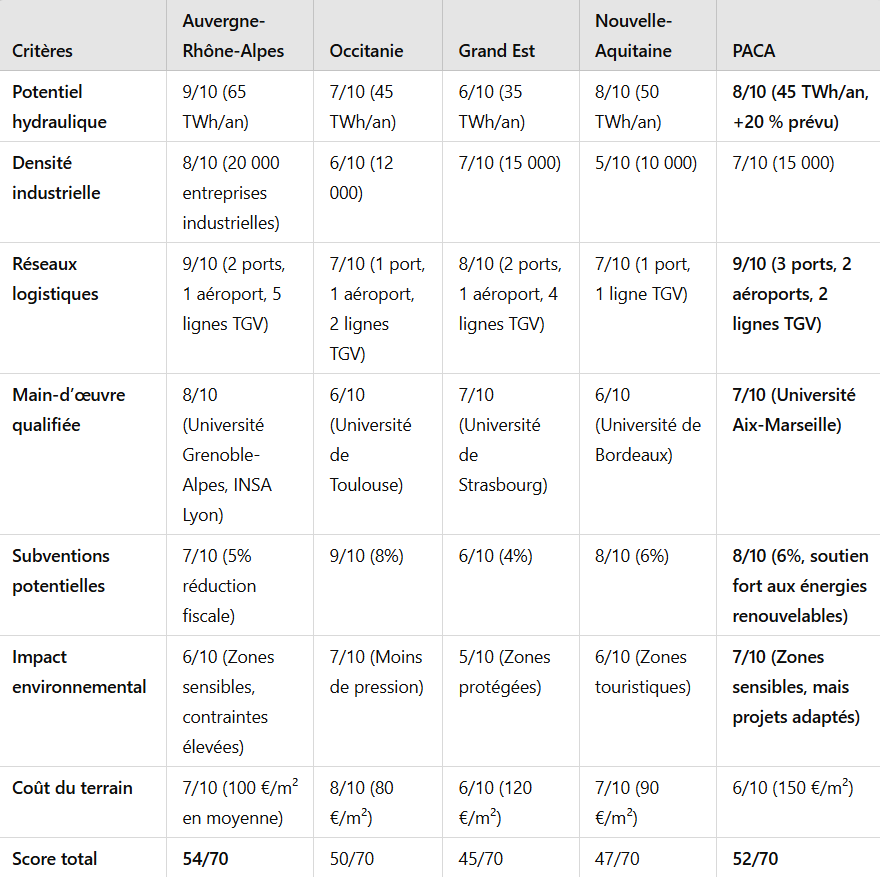
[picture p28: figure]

Figure 7.1: Comparison of potential French regions for turbine industrialisation and deployment.

The Kaplan principle was retained because the target sites combine low heads with relatively high and variable flow rates. The principal arguments are:

- suitability for heads below approximately 30 m and high discharge;
- high industrial efficiency, typically stated in the study as 90-95% under appropriate operating conditions;
- compatibility with modern regulation systems;
- robust operation over variable seasonal flow;
- potential for reduced environmental impact through controlled flow and blade-pitch operation;
- consistency with existing hydroelectric projects on rivers such as the Durance.

The study then compares large Kaplan installations with smaller modular units.
A compact bulb-turbine architecture is selected as the reference industrial product. This concept is well suited to low-head waterways, variable discharge, and modular deployment.

### 7.4 Sales and operations plan

The regional scenario targets an additional annual generation of approximately 2 TWh by 2030 through progressive installation of compact bulb turbines.
The reference unit is defined as follows.
Characteristic | Assumed value
nominal head | 1.5-10 m

### 32 Industrialisation and Market Deployment

Characteristic | Assumed value
unit power | 2 MW
maximum efficiency | 85-90%
estimated cost per turbine EUR 2 million
design life | 30-40 years

The assumed yearly output per turbine is

2 MW × 6000 h = 12 GWh/year. The number of turbines required for 2 TWh/year is therefore

Number of turbines =

2000
12

≈ 167.

The proposed five-year installation trajectory is:

Year | Turbines produced | Cumulative installed turbines | Cumulative annual production (GWh)
2025 | 33 | 33 | 396
2026 | 33 | 66 | 792
2027 | 33 | 99 | 1,188
2028 | 34 | 133 | 1,596
2029 | 34 | 167 | 2,004

The manufacturing concept includes five parallel assembly lines, each capable of completing one turbine approximately every two weeks. Critical runners and blades are machined locally, while certified suppliers provide generators and selected electronic systems.
The baseline staffing assumption is eight skilled operators and one supervisor per assembly line, supported by three maintenance technicians per site. The total annual production and maintenance workforce is approximately 60 people.
The principal raw-material assumptions per turbine are:
- 20 t of stainless steel;
- one generator and three principal sensors;
- biodegradable lubricants and associated auxiliary systems.

A safety stock equal to 10% of the cumulative installed fleet is proposed. This yields approximately three units in 2025 and 17 units in 2029.

### 7.5 Master production schedule

The master production schedule distributes 167 turbines over 60 months, with an average output of approximately three turbines per month.
The required production functions are:
- component machining;
- mechanical assembly;
- electrical-system integration;
- painting and surface treatment;
- quality control and acceptance testing.

The assumed installed resources include five CNC lines, three dedicated assembly stations, and two paint

Master production schedule 33

Figure 7.2: Comparison of turbine technologies for the selected regional conditions.

Figure 7.3: Large Kaplan units compared with smaller modular turbines.

### 34 Industrialisation and Market Deployment

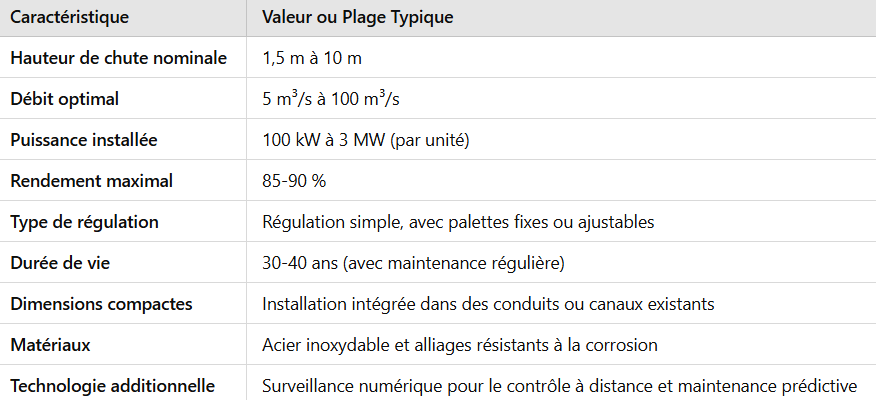
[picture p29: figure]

Figure 7.4: Compact bulb-turbine concept adopted for the industrial scenario.

Figure 7.5: Sales and operations plan, including annual production and safety stock.

booths. Planning is organised at three horizons: weekly scheduling for the first 12 months, quarterly review from 12 to 36 months, and annual adjustment from 36 to 60 months.

Year | Annual quantity | Quarterly quantity | Average monthly quantity
2025 | 33 | 8-9 | 2.75
2026 | 33 | 8-9 | 2.75
2027 | 33 | 8-9 | 2.75
2028 | 34 | 8-9 | 2.83
2029 | 34 | 8-9 | 2.83

For stainless steel, the total requirement is

| 20 t/turbine × 167 = 3340 t.
The original plan assumes quarterly steel deliveries of approximately 167 t, monthly electronic-system deliveries, and 50 kg of paint and surface-treatment products per turbine.
The labour model is summarised below.
Operation | Required operators Hours per turbine
component machining | 20 | 50
assembly | 30 | 40
painting and surface treatment | 10 | 20
quality control | 10 | 10
Total stated in the original schedule | 85 | 120

The operator total shown in the source schedule is retained, although the listed row values sum to 70. This

MRPII, MBOM, assembly, and plant flow 35

inconsistency should be resolved before an investment decision.
Key performance indicators include monthly output versus plan, defect rate with a target below 2%, and supplier delivery performance. Monthly production reviews and quarterly programme reviews are proposed.

### 7.6 MRPII, MBOM, assembly, and plant flow

The MRPII assumptions are:

- annual cadence: 33-34 turbines;
- working time: 35 hours per operator per week;
- two parallel teams;
- 220 working days per year;
- average stated manufacturing time: 150 hours per turbine.

For an average of three turbines per month, the required monthly operation times are:

- machining: 50 × 3 = 150 h/month;
- assembly: 40 × 3 = 120 h/month;
- painting and treatment: 20 × 3 = 60 h/month;
- quality control: 10 × 3 = 30 h/month.

One operator provides approximately

35 h/week × 4 = 140 h/month. The manufacturing bill of materials contains four principal families:

1. Main structure: turbine runner, main shaft, and casing.
2. Moving components: fixed and moving blades and rotational bearings.
3. Electrical systems: generator, control system, and automation hardware.
4. Auxiliaries: lubrication, anchors, and fasteners.

The reference per-turbine quantities are 20 tonnes of stainless steel, ten blades, 20 litres of biodegradable lubricant, one generator, and three sensors.
Assembly is divided into pre-assembly, final assembly, and testing. The runner and blades are assembled first, followed by the casing. The main shaft, bearings, generator, and auxiliary systems are then integrated. Mechanical checks, electrical calibration, and performance testing complete the process.
The available monthly production time for two teams is

35 h/week × 4 weeks/month × 2 = 280 h/month. For a demand of three turbines per month, the takt time is

Takt time =

280
3

= 93.33 h/turbine.

The stated direct lead time is

50 + 40 + 20 + 10 = 120 h/turbine. Because the lead time exceeds the takt time, the plan relies on parallel resources and overlapping operations. This relationship should be tested with a discrete-event model before finalising the line capacity.
The intended production flow is:
1. receipt of steel and electrical systems;
2. machining of metallic components;
3. pre-assembly of subassemblies;
4. transfer to final assembly;

### 36 Industrialisation and Market Deployment

5. painting and surface treatment;
6. final test;
7. central storage and delivery to the installation site.

The cost breakdown retained in the study is:

| Cost item | Cost per turbine Share
machining | EUR 0.8 million | 40%
assembly | EUR 0.6 million | 30%
electrical systems | EUR 0.4 million | 20%
surface treatment and quality | EUR 0.2 million | 10%
Total | EUR 2.0 million | 100%

For 167 turbines,

167 × EUR 2 million = EUR 334 million. The plant layout places CNC machines close to raw-material storage, aligns assembly stations to minimise transfers, isolates paint booths for environmental compliance, and centralises critical-component and finishedproduct storage.

### 7.7 Make-or-buy strategy

The make-or-buy analysis distinguishes performance-critical parts from standard or specialist components.

Component | Make | Buy | Rationale
turbine runner | internal machining | - | direct control of quality and geometry, at higher capital cost
fixed and moving blades | internal production | - | dimensional flexibility and performance control
casing | - | local supplier | lower cost, with supplier dependency
electrical generator | - | qualified supplier | access to specialist capability, with lead-time risk
control systems | - | specialist partners | expertise and certification requirements
lubrication system | internal integration | - | environmental and system-level control

The recommended strategy is mixed: manufacture the runner, blades, and other performance-critical elements internally; source standard or specialist components such as generators, casings, and control electronics.

### 7.8 Country-location strategy

The location criteria are labour cost, access to raw materials, industrial infrastructure, proximity to target sites, and political and economic stability.

Profitability analysis 37

Country | Advantages | Disadvantages
France | proximity to installation sites; strong industrial expertise and quality control | high labour cost
Poland | competitive labour cost; developed industrial infrastructure

moderately more complex logistics

Turkey | highly competitive metal-processing cost; good access to steel

greater transport distance

China | very low cost for standard
components; extensive industrial capacity

long lead times, quality risk, and trade exposure

Portugal | balanced labour cost and
European proximity

somewhat lower heavy-industrial capacity

The recommended configuration retains critical machining in France and outsources selected standard components to Poland or Turkey. The source study estimates approximately EUR 2.5 million per turbine for an all-France solution and EUR 2.0 million for the mixed strategy.

### 7.9 Profitability analysis

The commercial assumptions are:

- selling price: EUR 3 million per turbine;
- total sales: 167 turbines;
- total revenue: 167 × 3 = EUR 501 million;
- manufacturing cost: EUR 2 million per turbine;
- total manufacturing cost: 167 × 2 = EUR 334 million;
- R&D and initial investment: EUR 30 million;
- fixed costs over five years: EUR 50 million.

The gross margin per turbine is

EUR 3 million − EUR 2 million = EUR 1 million. The total gross margin is

167 × EUR 1 million = EUR 167 million. The total net profit is

EUR 501 million − (EUR 334 million + EUR 30 million + EUR 50 million) = EUR 87 million. The return on investment is

ROI =

Net profit
Total investment × 100,

ROI = 87
334 + 30 + 50

× 100 ≈ 21.5%.

With an annual gross margin of approximately

33 turbines/year × EUR 1 million/turbine = EUR 33 million/year,

### 38 Industrialisation and Market Deployment

the payback period on the EUR 80 million of R&D and fixed costs is

Payback =

30 + 50
33

≈ 2.4 years.

Indicator | Value
total revenue | EUR 501 million
total cost | EUR 414 million
total net profit | EUR 87 million
ROI | 21.5%
payback period | 2.4 years

Under these assumptions, the project is profitable, with a gross margin of EUR 1 million per turbine and a relatively short payback period. The result remains highly sensitive to sales volume, manufacturing cost, installation scope, financing, warranty exposure, and the realism of the 6000 h/year utilisation assumption. A subsequent investment-grade study should therefore include a discounted cash-flow model, uncertainty ranges, and scenario analysis.

CHAPTER 8

# Conclusion

This project demonstrates a complete multidisciplinary workflow for the design, analysis, prototyping, and industrial positioning of a compact axial hydraulic turbine.
The hydraulic pre-design established a 1500 rpm operating point, a design head of 3.8 m, a volume flow rate of 0.132 m³
.s

−1
, and a runner outer radius of 0.103 m. MATLAB and the Cordier diagram provided the principal similarity parameters, while the velocity-triangle calculations supplied the blade inlet and outlet angles. A modified NACA thickness law was fitted to obtain a blade profile with improved mechanical robustness.
The analytical geometry was transferred to CATIA V5, where the blade surfaces, runner, hub, duct, and fluid domains were constructed. A preliminary finite-element analysis confirmed that the largest stresses occur at the blade root and remain within the assumed elastic limit. STAR-CCM+ simulations then provided a first assessment of the velocity and pressure fields, convergence behaviour, power, efficiency, and cavitationsensitive regions. The best simulated point delivered approximately 1760 W at 0.144 m³
.s

−1
, indicating that the
original 5 kW target would require either a redesigned runner, different operating conditions, or a multi-unit architecture.
The electromechanical study derived the induced phase voltages and electromagnetic torque of a surface-mounted permanent-magnet synchronous generator. Magnet thickness, fundamental air-gap flux density, current loading, thermal constraints, and active length were linked in a consistent first-order model. The associated voltage-source inverter study showed the expected compromise between PWM carrier frequency, current ripple, semiconductor switching losses, and filter requirements. Vector current control in the d-q frame provided the required decoupling between flux and torque production.
The additive-manufacturing stage converted the CAD model into a physical PLA prototype. Wind-tunnel testing identified a maximum power coefficient of approximately 0.239 and a maximum experimental efficiency of approximately 0.56. These values are not directly equivalent to full-scale hydraulic performance, but they validate the existence of a measurable optimum and highlight the importance of surface finish, scale effects, clearances, and dynamic similitude.
Finally, the industrial analysis translated the concept into a modular deployment scenario based on 167 compact bulb turbines and a target generation of roughly 2 TWh/year. The proposed production plan, makeor-buy strategy, and mixed France-European sourcing model yield a stated ROI of 21.5% and a payback period of 2.4 years under the source assumptions. The exercise reveals both the potential of the concept and the need for stricter reconciliation of production times, staffing totals, commercial scope, and financial uncertainty before industrial commitment.
The principal value of the work lies in the continuity of the engineering chain: similarity-based hydraulic sizing informs the blade geometry; CAD and structural analysis prepare the numerical flow model; CFD informs the generator and prototype stages; and the resulting technical definition supports production and business planning. Future work should prioritise a refined transient CFD model, water-loop testing, structural fatigue analysis, generator finite-element validation, and a scenario-based industrial business case.

39

CHAPTER A

# MATLAB and XFoil Routines

The principal routines used for hydraulic preliminary sizing, blade mean-line construction, profile fitting, and point-cloud export are reproduced below. Comments have been translated into English; the mathematical operations and numerical coefficients are retained from the source implementation.

clear all; close all; clc

%%%%%%%%%%%%%%%%%%%%%%%%%%%%%%%%%%%%%%%%%%%%%%%%%%%%%%%%%%%%%%%%%%%%%%%%%%%

%Preliminary sizing of an axial turbine

7 | % | - Complete the following script and the functions it calls
9 | % | - Execute line by line using the F9 key

%%%%%%%%%%%%%%%%%%%%%%%%%%%%%%%%%%%%%%%%%%%%%%%%%%%%%%%%%%%%%%%%%%%%%%%%%%%

% options

Nom='marim';%Turbine name

%constants

g=9.81; %m^2/s

%%%%%%%%%%%%%%%%%%%%%%%%%%%%%%%%%%%%%%%%%%%%%%%%%%%%%%%%%%%%%%%%%%%%%%%%%%%

%Design specification

%%%%%%%%%%%%%%%%%%%%%%%%%%%%%%%%%%%%%%%%%%%%%%%%%%%%%%%%%%%%%%%%%%%%%%%%%%%

N=1500;%rpm

%Q1: Determine the angular velocity

omega=N*2*pi/60;%rad/s

Re=0.103;% penstock radius and turbine outer radius

Nsq=200;%engineering specific speed

%Q2: Determine the angular velocity

vas=Nsq*2*pi/60/g^.75;%specific angular velocity

disp(vas);

vas = Nsq*2*pi/60/g^.75; % specific speed

%% Sizing using the Cordier diagram

% q1 determine the specific radius from the Cordier diagram

Lambda = 0.701;

% q2 - Determine the head parameters (H and qv) as functions of % vas, Lambda, and R

41

53
54 %%%%%%%%%%%%%%%%%%%%
55
56 % graphical solution for H
57
58 H = 0.1:0.1:10; % definition of a variable
59
60 | A = vas/omega*(g*H).^.75 - Re/Lambda*(g*H).^0.25; % exploitation
61 | % of the two-equation system
62
63 figure(2);
64
65 plot(H, A, 'b');
66
67 line([0 10], [0 0]);
68
69 xlabel('H (m)');
70
71 ylabel('A');
72
73 clear H;
74
75 %therefore
76
77 H=3.8;% design head
78
79 % deduce qv
80
81 qv=(Nsq*H^0.75/N)^2;
82
83 disp(qv);
84
85 %%%%%%%%%%%%%%%%%%%%%%%%%%%%%%%%%%%%%%%%%%%%%%%%%%%%%%%%%%%%%%%%%%%%%%%%%%% 86
87 %% Global preliminary sizing of the runner
88
89 Za = 6; % number of blades
90
91 eta = 0.92; % hydraulic efficiency 92
93 % aspect ratio T = Ri/Re:
94
95 T = 0.38;
96
97 Ri = Re*T;
98
99 Ri = floor(1000*Ri)/1000; % rounded to the nearest millimetre 100
101 disp('Re (m), Ri (m)');
102
103 disp([Re Ri]);
104
105 % q5: Create a series of five radii from Ri to Re to discretise 106
107 % the blade angle (rounded to the nearest millimetre)
108
109 nr = 5; % number of radial discretisation points 110
111 r = linspace(Ri, Re, nr);
112
113 r = floor(r*1000)/1000;
114
115 %%%%%%%%%%%%%%%%%%%%%%%%%%%%%%%%%%%%%%%%%%%%%%%%%%%%%%%%%%%%%%%%%%%%%%%%%%% 116
117 % Blade velocity triangles and runner-blade plotting
118

### 42 MATLAB and XFoil Routines

119 %%%%%%%%%%%%%%%%%%%%%%%%%%%%%%%%%%%%%%%%%%%%%%%%%%%%%%%%%%%%%%%%%%%%%%%%%%% 120
121 %Q6: Calculate the axial flow component of fluid velocity (Ca) from
122
123 % qv, Re, and Ri
124
125 Ca = qv / (pi * (Re^2 - Ri^2)); 126
127 disp(Ca);
128
129 %%%%%%%%%%%%%%%%%%%%%%%%%%%%%%%%%%%%%%%%%%%%%%%%%%%%%%%%%%%%%%%%%%%%%%% 130
131 %Definition of blade sections at radius r(u)
132
133 %%%%%%%%%%%%%%%%%%%%%%%%%%%%%%%%%%%%%%%%%%%%%%%%%%%%%%%%%%%%%%%%%%%%%%% 134
135 % Complete the loop that defines the nr sections line by line
136
137 %sections
138
139 % NOTE: during the first pass, disable "for" and "end" for debugging 140
141 % for-loop generating the nr intermediate blade profiles
142
143 % for-loop generating the nr intermediate blade profiles 144
145 for u = 1:size(r, 2)
146
147 | %u=1
148
149 | % Q7: At the current radius r, calculate the kinematic components U(r),
150 | % and Cu2_th(r)
151
152 | % then Cu2(r), accounting for hydraulic efficiency eta (recall that
153 | %
154
155 | % the machine is purely axial: Ca(r)=Ca1(r)=Ca2(r) and U(r)=
156 | % U1(r)=U2(r)
157
158 | U = omega*r(u);
159
160 | Cu2_th = -g*H/U; % (Euler theorem)
161
162 | Cu2 = Cu2_th*eta;
163
164 | % Q8: Determine the blade inlet angle beta_1 and outlet angle
165 | % beta_2
166
167 | beta_1 = atand(U/Ca);
168
169 | beta_2 = atand((U - Cu2)./Ca);
170
171 | % the discharge angle alpha_2,
172
173 | alph_2 = atand(Ca/Cu2);
174
175 | % Display values in the Command Window for verification.
176 | % Accept beta_1 and beta_2 within the range [30 deg, 80 deg].
177
178 | if u==1; disp('check: r(u) | beta_1 | beta_2 | alph_2');end;
179
180 | disp([r(u) beta_1 beta_2 alph_2]);
181
182 | %%%%%%%%%%%%%%%%%%%%%%%%%%%%%%%%%%%%%%%%%%%%%%%%%%%%%%%%%%%%%%%%%%%
183
184 | %Mean-line processing

43

185
186 | %%%%%%%%%%%%%%%%%%%%%%%%%%%%%%%%%%%%%%%%%%%%%%%%%%%%%%%%%%%%%%%%%%%
187
188 | %Discretisation of the unit axial-extent mean line xx
189
190 | %Refine near the leading edge
191
192 | %arbitrary discretisation that may be modified
193
194 | xba=[0,logspace(-6,-2,10)];% leading-edge region
195
196 | xmc=linspace(0.011,0.1,9);% mid-chord region
197
198 | xbf=linspace(0.11,1,9);% trailing-edge region
199
200 | xx=[xba xmc xbf];
201
202 | % Calculate the mean line using the ligneK function
203
204 | %%%%%%%%%%%%%%%%%%%%%%%%%%%%%%%%%%%%%%%%%%%%%%%%
205
206 | %Q9: Edit and complete the LigneK script before executing the
207
208 | %following command
209
210 | [yy,beta_i]=ligneK(beta_1,beta_2,xx);
211
212 | %Plot the unit axial-extent mean line
213
214 | figure (2); hold on;
215
216 | plot(xx,yy,'r');xlabel('xx[ ]');ylabel('yy[ ]');
217
218 | legend('unit axial-extent mean line');
219
220 | axis equal
221
222 %%%%%%%%%%%%%%%%%%%%%%%%%%%%%%%%%%%%%%%%%%%%%%%%%%%%%%%%%%%%%%%%%%%%%%%%%%%%%%%% 223
224 | %Thickness distribution along the mean line
225
226 %%%%%%%%%%%%%%%%%%%%%%%%%%%%%%%%%%%%%%%%%%%%%%%%%%%%%%%%%%%%%%%%%%%%%%%%%%%%%%%% 227
228 | %Q10: Set the radial variation of relative thickness tt(r) from the root
229 | %of the blade (arbitrarily 13%) to the tip (arbitrarily 3%).
230 | %
231
232 | %This distribution may be improved at the end of the practical session
233
234 | ep_pied=13/100;
235
236 | ep_peri=3/100;
237
238 | tt=linspace(ep_pied,ep_peri,nr);
239
240 | figure (3);hold on;
241
242 | legend('thickness law')
243
244 | plot(r,tt);
245
246 | xlabel('r(m)');ylabel('ep(%)');
247
248 | %tt=[0.16 0.11 0.08 0.05 0.03];% an alternative tt(r) variation
249
250 | %Q11: Answer Questions Q11.1 and Q11.2. Edit the epaisseurK function

### 44 MATLAB and XFoil Routines

251
252 | %and complete its script to answer Question Q11.3
253
254 | [xp1 yp1 xp2 yp2]=epaisseurK(xx,yy,beta_i,tt(u));
255
256 | %transpose into column vectors
257
258 | xp1=xp1'; yp1=yp1';
259
260 | xp2=xp2'; yp2=yp2';
261
262 | figure (4); hold on;
263
264 | plot(xp1,yp1,'b')
265
266 | plot(xp2,yp2,'g')
267
268 | axis equal
269
270 %%%%%%%%%%%%%%%%%%%%%%%%%%%%%%%%%%%%%%%%%%%%%%%%%%%%%%%%%%%%%%%%%%%%%%% 271
272 | %Blade-row solidity
273
274 %%%%%%%%%%%%%%%%%%%%%%%%%%%%%%%%%%%%%%%%%%%%%%%%%%%%%%%%%%%%%%%%%%%%%%%
275
276 | %Q12: Recall the definition and role of solidity, including its benefits and drawbacks.
277
278 | %drawbacks of high solidity.
279
280 | serrage=0.6;
281
282 | lx=serrage*(2*pi*r(u)/6);%chord length
283
284 | xp1=xp1*lx; yp1=yp1*lx;%scale the profiles
285
286 | xp2=xp2*lx; yp2=yp2*lx;
287
288 | zz=ones(size(xx')).*r(u);%for 3D plotting
289
290 | %for visualisation
291
292 | figure (5); hold on;
293
294 | plot3(xp1,yp1,zz,'r')
295
296 | plot3(xp2,yp2,zz,'k')
297
298 | %Additionally, plot the Ri and Re envelope circles
299
300 | %angular discretisation
301
302 | theta=0:0.01:2*pi;
303
304 | yri=Ri*cos(theta);
305
306 | zri=Ri*sin(theta);
307
308 | xri=zeros(1,size(theta,2));
309
310 | plot3(xri,yri,zri);
311
312 | plot3(xri,yri/Ri*Re,zri/Ri*Re);
313
314 | axis equal
315
316 | view(120,16)

45

317
318 %%%%%%%%%%%%%%%%%%%%%%%%%%%%%%%%%%%%%%%%%%%%%%%%%%%%%%%%%%%%%%%%%%%%%%% 319
320 | %projection of the profile onto the hub
321
322 %%%%%%%%%%%%%%%%%%%%%%%%%%%%%%%%%%%%%%%%%%%%%%%%%%%%%%%%%%%%%%%%%%%%%%% 323
324 | %projection angles
325
326 | the21=yp1./unique(zz);
327
328 | the22=yp2./unique(zz);
329
330 | %initialise a zero matrix for each envelope
331
332 | XXext=zeros(size(xx,2),3); XXint=zeros(size(xx,2),3);
333
334 | %cylindrical projection
335
336 | XXext(:,1)=xp1;
337
338 | XXint(:,1)=xp2;
339
340 | XXext(:,2)=r(u)*cos(the21);
341
342 | XXint(:,2)=r(u)*cos(the22);
343
344 | XXext(:,3)=r(u)*sin(the21);
345
346 | XXint(:,3)=r(u)*sin(the22);
347
348 | % final plot
349
350 | figure (6); hold on;
351
352 | plot3(xri,yri,zri);
353
354 | plot3(xri,yri/Ri*Re,zri/Ri*Re);
355
356 | plot3(XXext(:,1),XXext(:,2),XXext(:,3),'b')
357
358 | plot3(XXint(:,1),XXint(:,2),XXint(:,3),'g')
359
360 | axis equal
361
362 | view(-30,0)% viewpoint
363
364 | %Blade replication
365
366 | traceZpales(XXext,Za,[0 0 0]);
367
368 | traceZpales(XXint,Za,[1 0 0]);
369
370 | view(100,60)
371
372 %%%%%%%%%%%%%%%%%%%%%%%%%%%%%%%%%%%%%%%%%%%%%%%%%%%%%%%%%%%%%%%%%%%%%%%%%%% 373
374 | %create a structure for storing the CATIA point clouds
375
376 | XXX.ext(u).R=XXext*1000;
377
378 | XXX.int(u).R=XXint*1000;
379
380 end
381
382 %%%%%%%%%%%%%%%%%%%%%%%%%%%%%%%%%%%%%%%%%%%%%%%%%%%%%%%%%%%%%%%%%%%%%%%%%%%

### 46 MATLAB and XFoil Routines

%Generate an export file for CATIA

Nom='Courbes-GSD';%Excel file name

TableauGSD={'StartLoft','',''};

for u=1:nr

%upper surface

TableauGSD=[TableauGSD ; {'StartCurve','',''}];

for k=1:length(XXX.ext(u).R)

TableauGSD=[TableauGSD ;
{XXX.ext(u).R(k,1),XXX.ext(u).R(k,2),XXX.ext(u).R(k,3)}];

end

TableauGSD=[TableauGSD ; {'EndCurve','',''}];

%lower surface

TableauGSD=[TableauGSD ; {'StartCurve','',''}];

for k=1:length(XXX.int(u).R)

TableauGSD=[TableauGSD ;
{XXX.int(u).R(k,1),XXX.int(u).R(k,2),XXX.int(u).R(k,3)}];

end

TableauGSD=[TableauGSD ; {'EndCurve','',''}];

end

TableauGSD=[TableauGSD ; {'EndLoft','',''}];

TableauGSD=[TableauGSD ; {'End','',''}];

xlswrite(Nom,TableauGSD); % copy these data into the CATIA file
% GSD_PointSplineLoftFromExcel.xls, which contains the import macro.

Listing A.1: Axial-turbine preliminary sizing and CATIA point-cloud export routine.

%Find an analytical expression for profiles whose

%trailing edge is thickened to ensure mechanical strength.

% Input: point file generated by XFOIL (\"psave\")

% Tool: MATLAB fminsearch or lsqcurvefit if the Optimization Toolbox is available.

clear all; close all; clc;

%Q11.21: enter the filename and corresponding relative thickness

fname='NACA0015_DEV_KUMAR.txt';

tt=0.15;%relative thickness of the profile to load

data=load(fname);%load the file

figure(1);hold on;%plot raw points

47

plot(data(:,1),data(:,2));

axis equal

%Q11.22: Define xdata and ydata for the upper surface (first half of the file points).

xdata=data(1:ceil(239/2),1);

ydata=data(1:ceil(239/2),2);

plot(xdata,ydata,'g-');% plot in red

%Q11.23: Plot the unmodified NACA thickness law; its coefficients initialise the fit.

naca0=[0.2969 -0.1260 -0.35116 +0.2843 -0.1015]; % standard NACA coefficients

% define the fonc_naca function with:

% tt=relative thickness, %

% x=chordwise abscissae

% Variables are defined inside @(), followed by the function expression.

fonc_naca=@(naca,x) tt/0.2*(naca(1)*x.^0.5+naca(2)*x+naca(3)*x.^2+naca(4)*x.^3+naca(5)*x.^4);

y0=fonc_naca(naca0,xdata); % recover the thickness distribution from naca0

plot(xdata,y0,'m-');%plot in green

%Q11.24: Configure fminsearch to obtain the new coefficients.

% The new ecartq function (sum of squared differences between % data and model) is minimised to define the coefficients of the

% modified profile

ecartq= @(naca) sum((ydata-fonc_naca(naca,xdata)).^2);

naca_mod=fminsearch(ecartq, naca0);%See the fminsearch documentation

disp(naca_mod);%display the coefficients

plot(xdata,fonc_naca(naca_mod,xdata),'r*:') % zoom in to compare data and model

Listing A.2: Modified NACA thickness-law identification routine.

function [yy,beta_i]=ligneK(beta_1,beta_2,xx)

%plots the mean lines yy=f(xx) of the blade sections:

%with:

% inputs:

% beta_1:inlet angle

% beta_2:outlet angle

% xx normalised abscissae

% outputs:

% yy ordinates

### 48 MATLAB and XFoil Routines

18
19 | % beta_i angles
20
21 %boundary conditions:
22
23 | % linear variation of local angle beta_i between beta_1 and beta_2
24
25 %define:
26
27 | % dyy local variation
28
29 %%%%%%%%%%%%%%%%%%%%%%%%%%%%%%%%%%%%%%%%%%%%%%%%%%%%%%%%%%%%%%%%%%%%%%%%%%% 30
31 %Q :Define dyy=f(xx), then yy=f(xx)
32
33 | dyy=(tand(beta_2)-tand(beta_1)).*xx+tand(beta_1);
34
35 | yy=0.5*(tand(beta_2)-tand(beta_1)).*xx.^2+tand(beta_1).*xx;
36
37 %%%%%%%%%%%%%%%%%%%%%%%%%%%%%%%%%%%%%%%%%%%%%%%%%%%%%%%%%%%%%%%%%%%%%%%%%%% 38
39 %Q :Define the local angle beta_i=f(dyy)
40
41 | beta_i=atand(dyy);
42
43 end

Listing A.3: Blade-section mean-line generator.

1 function [xp1 yp1 xp2 yp2]=epaisseurK(xx,yy,bei,tt) 2
3 %distributes the NACA thickness along the mean lines 4
5 %with:
6
7 | % inputs:
8
9 | % xx: normalised mean-line abscissae (0 to 1)
10
11 | % yy: mean-line ordinates based on xx
12
13 | % beta_i: local angle
14
15 | % tt: relative thickness
16
17 | % outputs:
18
19 | % xp1 and yp1: upper-surface point coordinates
20
21 | % xp2 and yp2: lower-surface point coordinates
22
23 %Q11.3: Enter the yt polynomial coefficients in the row vector naca. 24
25 %See the Loi_Ep2.m script to determine them
26
27 | %naca=[0.3025 | -0.1350 | -0.3610 | 0.2887 | -0.0781];
28
29 | naca=[0.2947 | -0.1129 | -0.3719 | 0.3214 | -0.0981];
30
31 | %naca=[0.2969 -0.1260 -0.35116 | 0.2843 -0.1015];%standard coefficients
32
33 yt=tt/0.2*(naca(1)*xx.^0.5+naca(2)*xx+naca(3)*xx.^2+naca(4)*xx.^3+naca(5)*xx.^4); 34
35 %%%%%%%%%%%%%%%%%%%%%%%%%%%%%%%%%%%%%%%%%%%%%%%%%%%%%%%%%%%%%%%%%%%%%%%%%%%
36

Software environment and model scope 49

%%%%%%%%%%%%%%%%%%%%%%%%%%%%%%%%%%%%%%%%%%%%%%%%%%%%%%%%%%%%%%%%%%%%%%%%%%%

% Calculate local chord length cc for scaling

cc=(xx(end)^2+yy(end)^2).^0.5;

% Calculate the coordinates of each envelope point

%upper surface xp1, yp1

xp1=xx-cc*yt.*sind(bei);

yp1=yy+cc*yt.*cosd(bei);

%lower surface: xp2, yp2

xp2=xx+cc*yt.*sind(bei);

yp2=yy-cc*yt.*cosd(bei);

% normalise by the chord length

xp1=xp1/cc;

yp1=yp1/cc;

xp2=xp2/cc;

yp2=yp2/cc;

end

Listing A.4: Blade-thickness distribution about the mean line.

### A.1 Software environment and model scope

The study combines MATLAB for numerical sizing and data processing, XFoil for section-profile manipulation, CATIA V5 for surface and solid modelling, STAR-CCM+ for computational fluid dynamics, SIMBA for the electromechanical drive and PWM investigations, and PrusaSlicer for additive-manufacturing preparation. Each numerical stage is a preliminary engineering model and should be interpreted within the assumptions stated in the corresponding chapter. In particular, the steady moving-reference-frame CFD model, the two-dimensional magnetic approximation, the wind-tunnel similarity experiment, and the high-level industrial business case are complementary design tools rather than substitutes for full-scale qualification.

# Integrated Turbomachinery Design

Hydraulics · Mechanical Design · CFD · Electrical Conversion · Prototyping · Industrialisation

Research Edition · 2024

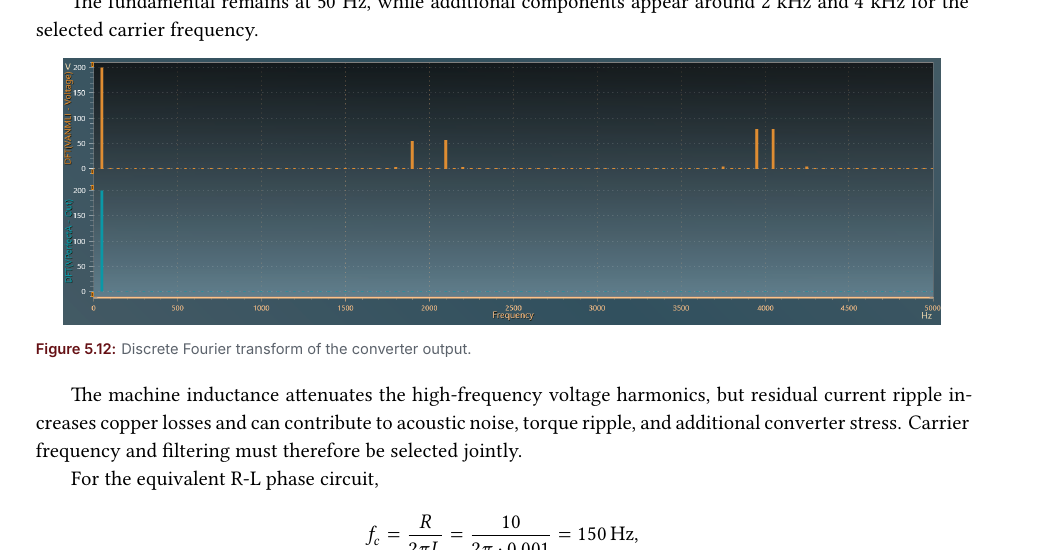
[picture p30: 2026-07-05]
assets/converter_dft_spectrum.png

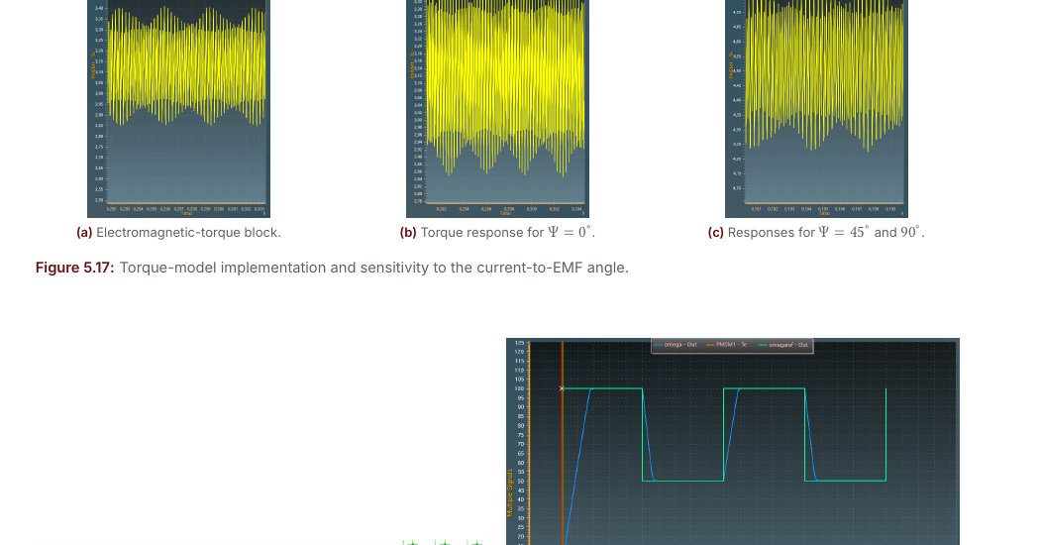
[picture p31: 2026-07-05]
assets/torque_control_response.png

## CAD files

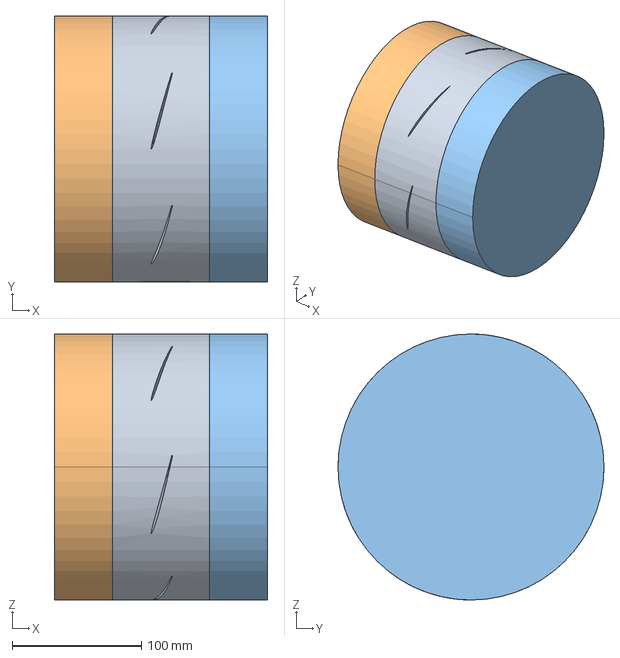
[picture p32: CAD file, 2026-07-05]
cad/fluid_domain_part2.stp
165.0 x 206.0 x 206.0 mm

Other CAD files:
cad/fluid_domain_part1.stp

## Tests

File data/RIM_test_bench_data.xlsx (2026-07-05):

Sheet: 1500
N
1500
 | qv | dP | dH | P_mec | Eta
 | 455 | 19300 | 1.967380224 | 1.47 | 60.2
 | 470 | 22800 | 2.324159021 | 1.86 | 62.5
 | 490 | 27800 | 2.833843017 | 2.402 | 63.87
 | 500 | 30100 | 3.068297655 | 2.68 | 64
 | 510 | 32740 | 3.337410805 | 2.968 | 64
 | 520 | 35400 | 3.608562691 | 3.26 | 63.85
 | 550 | 43600 | 4.444444444 | 4.173 | 62.8
 |  |  |  |  |  | d’où | qvn1= | 0.1388888889
 |  |  |  |  |  |  | Hn1= | 3.07
 |  |  |  |  |  |  | Pn1= | 2680
 |  |  |  |  |  |  |  |  | N2 | 1732.050808
 |  |  |  |  |  |  | qv |  | qv2 | 577.3502692

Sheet: 1700
N
1700
 | qv | dP | dH | P_mec | Eta
 | 520 | 25900 |  | 2960 | 61.4
 | 550 | 33900 | 3.455657492 | 3320 | 64
 | 560 | 36700 | 3.74108053 | 3678 | 64.3
 | 580 | 42600 | 4.342507645 | 4410 | 64.3
 | 600 | 48600 | 4.95412844 | 5170 | 63.8
 | 640 | 61000 | 6.21814475 | 6770 | 62.3

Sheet: 2200
N
2200
 | qv | dP | dH | P_mec | Eta
 | 650 |  |  |  | 58.7
 | 720 | 59800 | 6.095820591 | 7750 | 64.8
 | 760 | 74900 | 7.635066259 | 10220 | 64.6

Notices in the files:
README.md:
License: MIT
